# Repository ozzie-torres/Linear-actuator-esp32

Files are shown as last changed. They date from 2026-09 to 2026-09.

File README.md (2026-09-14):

# ESP32 Linear Actuator Controller

PlatformIO/Arduino firmware for independently testing two STEP/DIR/ENABLE
stepper axes from a responsive web interface. Motion is generated by
FastAccelStepper using the ESP32 MCPWM/PCNT peripherals, so Wi-Fi requests do
not determine pulse timing.

This repository has two deliberate roles:

1. `src/main.ino` is the working hardware bring-up and diagnostic firmware. It
   verifies wiring, directions, limits, speeds, and mechanics without pretending
   to be a CNC controller.
2. `fluidnc/config.yaml` is the validated migration configuration for FluidNC,
   which will provide proper homing, coordinated X/Y interpolation, machine and
   work coordinates, and G-code file execution.

## Current project state and handoff

As of 2026-09-14, the hardware has completed both diagnostic-firmware bring-up
and FluidNC commissioning. Official FluidNC v4.0.3, its WebUI filesystem, and
`fluidnc/config.yaml` are installed on the ESP32. Both axes move reliably, both
limit inputs have been electrically and mechanically verified, negative machine
motion travels toward the minimum/home switches, and FluidNC's complete `$H`
cycle succeeds in X-then-Y order. A final coordinate test moved X and Y from
machine zero to 5.000 mm and returned both to 0.000 mm with the controller Idle.
The WebUI then uploaded `gcode/first_motion_test.gcode` to LocalFS; FluidNC ran
it through `$LocalFS/Run`, reported `Program End`, and returned to Idle at X0/Y0.

The A4988 MS1/MS2/MS3 DIP switches are now all ON for 1/16 microstepping. Each
axis uses a 1.8-degree, 200-step/revolution NEMA-17, a GT2 belt, and a 20-tooth
pulley. Therefore:

```text
200 full steps/rev * 16 microsteps / (20 teeth * 2 mm) = 80 steps/mm
1 microstep = 0.0125 mm commanded resolution
```

Measured travel from the home position to the opposite mechanical end is 520 mm
on X and 460 mm on Y. FluidNC intentionally uses smaller 510 mm and 450 mm
software travels, leaving 10 mm before each positive mechanical end. Earlier
96.5 mm X and approximately 100 mm Y observations were calibration moves, not
the full machine envelope.

The official FluidNC v4.0.3 Windows bundle and current official validator are
available locally under ignored `.tools/`. `fluidnc/config.yaml` passes the
official validator and is the configuration currently running on the machine.
FluidNC station credentials are stored in ESP32 nonvolatile settings rather
than this repository. At commissioning time it joined the local network at
`http://10.0.0.68/` and advertised `http://fluidnc-stage.local/`; DHCP may assign
a different numeric address later.

## Hardware

| Signal | ESP32 pin | Notes |
| --- | ---: | --- |
| X STEP | GPIO 25 | MCPWM-generated pulse output |
| X DIR | GPIO 26 | Positive/negative X direction |
| X ENABLE | GPIO 27 | Active LOW; enabled after safe initialization |
| Y STEP | GPIO 16 | MCPWM-generated pulse output |
| Y DIR | GPIO 17 | Positive/negative Y direction |
| Y ENABLE | GPIO 22 | Active LOW; enabled after safe initialization |
| X minimum/home switch | GPIO 32 | NO contact to GND; internal pull-up |
| Y minimum/home switch | GPIO 13 | NO contact to GND; internal pull-up |

Connect ESP32 ground to the stepper driver's logic/power ground. Never connect
or disconnect motor coils while the driver is powered. Set the driver's current
limit for the connected motor before extended operation.

Each normally-open limit switch connects only its assigned GPIO to GND when
pressed. The internal pull-up makes an unpressed switch read HIGH and a pressed
switch read LOW, so no external resistor is required. The manual API blocks
negative motion while its minimum switch is pressed, but permits positive
motion so the operator can back away. NO wiring is minimal but not fail-safe: a
broken wire looks like an unpressed switch. GPIO 18/19/23/5 are deliberately
reserved for a future VSPI SD card.

Both FluidNC direction pins use plain polarity (`gpio.26` and `gpio.17`). During
commissioning, the earlier inverted X setting moved away from home; removing
`:low` made negative coordinate motion travel toward each switch. Revalidate
this behavior if any motor leads, driver connections, or transmission changes.

### Motion hardware

- Two A4988 StepStick drivers, configured by carrier-board DIP switches
- MS1, MS2, and MS3 all ON: 1/16 microstepping
- Two 1.8-degree NEMA-17 motors (200 full steps/revolution)
- GT2 2 mm-pitch belts with 20-tooth pulleys
- X calibration: 80 steps/mm; physical travel: 520 mm; soft travel: 510 mm
- Y calibration: 80 steps/mm; physical travel: 460 mm; soft travel: 450 mm

## Build and configuration

1. Install PlatformIO.
2. Copy `src/secrets.example.h` to `src/secrets.h`.
3. Set the 2.4 GHz station credentials and direct access-point credentials.
4. Run `pio run` to build.
5. Run `pio run --target upload --upload-port COM4` (adjust the port as needed).
6. Use a 115200-baud serial monitor to read assigned IP addresses.

`src/secrets.h` is intentionally ignored by Git. If it is absent, the example
placeholder values are used so a clean checkout can still compile.

The only external Arduino library is pinned in `platformio.ini`:

- FastAccelStepper 0.31.8

## Diagnostic-firmware network behavior

The ESP32 starts in AP+station mode:

- It selects the strongest matching 2.4 GHz access point and retains the
  strongest WPA2-only radio as a compatibility fallback.
- It also exposes the configured direct AP, normally reachable at
  `http://192.168.4.1`.
- Station failure does not prevent the direct AP or web server from operating.

Wi-Fi station power saving is disabled to reduce interactive latency. The web
page also permits only one status request at a time, preventing slow polls from
accumulating ahead of motion commands on the synchronous ESP32 WebServer.

The installed FluidNC firmware uses station-with-AP-fallback mode (`STA>AP`),
DHCP, and hostname `fluidnc-stage`. Network credentials live in FluidNC NVS and
are intentionally absent from Git. Use the FluidNC WebUI, USB serial, or a G-code
sender for normal machine control; the custom HTTP API below belongs only to the
diagnostic firmware and is not served while FluidNC is installed.

## HTTP API

| Method | Path | Purpose |
| --- | --- | --- |
| GET | `/` | Embedded mobile control page |
| GET | `/status` | Nested X/Y position, motion, settings, and limit state |
| POST | `/move` | Relative move; `axis=x|y`, `direction=positive|negative` |
| POST | `/stop` | Controlled stop; `axis=x|y|all` |
| POST | `/zero` | Zero selected `axis=x|y` while stopped |
| POST | `/settings` | Apply settings to selected `axis=x|y` |

## Motion and position semantics

FastAccelStepper queues motion and produces pulses independently of Arduino's
`loop()`. `loop()` only services the synchronous web server. Position remains
open-loop: PCNT counts generated STEP pulses, but there is no encoder confirming
that the motor physically moved. STOP decelerates normally rather than removing
torque abruptly.

The future `homeStepper()` placeholder describes the intended switch sequence.
Implement it as a non-blocking state machine so web requests and STOP remain
responsive.

### Known diagnostic-firmware limitations

- `homeStepper()` is intentionally a documented placeholder; there is no
  automatic `/home` endpoint. The successful calibration homing was supervised
  using bounded API moves: seek, interrupt stop, 3 mm pull-off, slow approach,
  and `setCurrentPosition(0)`.
- Limit switches are normally open to minimize component count. A broken wire
  therefore looks like a safe, released switch. Normally-closed switches and a
  physical emergency stop are recommended before unattended machine use.
- The diagnostic ISR force-stops an axis on every falling limit edge, regardless
  of movement direction. Mechanical contact bounce can interrupt a move away
  from the switch; this was observed during pull-off and handled with a second
  bounded move. FluidNC replaces this temporary behavior with its homing logic.
- X and Y are independently commanded. This firmware does not calculate a
  coordinated line, arc, junction velocity, or tool path.
- Position is commanded open-loop position and resets when firmware restarts.
  There are no motor encoders.
- The drivers remain enabled after safe initialization to preserve holding
  position. A4988 current limits must be adjusted correctly, and driver/motor
  temperature must be monitored.
- There is currently no dedicated hardware emergency-stop input.

## CNC/G-code controller

The custom firmware remains an electrical and mechanical diagnostic tool; it
does not coordinate axes or interpret G-code. The machine has now migrated to
FluidNC, which provides coordinated interpolation, machine/work coordinates,
homing, hard/soft limits, WebUI control, and execution of uploaded or SD-card
G-code without maintaining a custom motion planner.

The validated migration configuration is in `fluidnc/config.yaml`. It records
the A4988 1/16 microstep setting, 20-tooth GT2 calibration (80 steps/mm),
commissioned direction polarity, conservative travel limits, and sequential X/Y
homing. Keep the diagnostic firmware in Git for future electrical troubleshooting;
reflashing it would replace FluidNC on the ESP32.

## FluidNC commissioning

Official FluidNC v4.0.3 was installed and tested. Review release notes and
revalidate the YAML before upgrading to another version. The running
configuration uses:

- ESP32 RMT hardware stepping
- Cartesian X/Y kinematics
- 80 steps/mm on both axes
- 750 mm/min initial maximum rate
- 10 mm/s^2 initial acceleration
- X then Y sequential two-pass homing
- 300 mm/min seek, 60 mm/min precision approach, and 3 mm pull-off
- 125% homing search distance on each axis. This does not expand the 510/450 mm
  soft-limited working envelopes; it only ensures homing can find a switch from
  anywhere inside the measured physical travel.
- Active-low inputs with internal pull-ups (`gpio.32:low:pu` and
  `gpio.13:low:pu`)
- A4988 active-high disable semantics on GPIO 27 and GPIO 22
- Hard limits, soft limits, and mandatory homing after restart

The 2026-09-14 commissioning record is:

1. Erased the ESP32 and installed the official Wi-Fi image plus WebUI filesystem.
2. Uploaded the validated YAML as `/littlefs/config.yaml`; the complete startup
   report parsed every assigned pin without an error.
3. With motor power off, pressed X and Y individually and observed `Pn:X` and
   `Pn:Y`; both cleared when released. `$MD` drove both active-low A4988 ENABLE
   inputs to the safe 3.3 V disabled level.
4. Initial X homing exposed reversed FluidNC direction polarity. X and Y were
   corrected to plain `gpio.26` and `gpio.17` direction pins.
5. X's initial 110% homing search expired a few millimeters before the switch.
   Both axes now use 125%, providing margin for a start at the far end.
6. `$HX` and `$HY` each completed their seek, pull-off, slow approach, and zero.
   A subsequent full `$H` reported `Homed:X`, then `Homed:Y`.
7. Final status was `Idle|MPos:0.000,0.000,0.000` with no active limit pins.
8. `G91 G1 X5 F300`, followed by `G1 Y5 F300`, produced machine position
   X5.000/Y5.000. `G90 G0 X0 Y0` returned both axes to machine zero.
9. Uploaded `gcode/first_motion_test.gcode` through the WebUI Local Filesystem
   panel. `$LocalFS/Show` verified its contents, and
   `$LocalFS/Run=first_motion_test.gcode` traced the 10 mm square, reported
   `Program End`, and finished Idle at machine X0/Y0 without an alarm.

Before the first real process, measure commanded travel accurately, refine
steps/mm if necessary, dry-run a small G-code file unloaded, and add a physical
normally-closed emergency stop. Open-loop step counts do not prove that the
mechanism moved without losing steps.

The standard VSPI pins GPIO 18/19/23/5 remain unused, allowing a later SD-card
interface. FluidNC can initially upload and run small G-code files from its
local flash filesystem, so an SD-card module is not required for first tests.

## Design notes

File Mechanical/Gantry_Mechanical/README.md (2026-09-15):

# Gantry mechanical source archives

These archives were copied without modification on 2026-09-14 from the local
project staging folder:

```text
C:\Users\oswak\Downloads\Gantry_Mechanical
```

They are retained as source/reference material for the mechanical gantry. Keep
the archives intact so their included documentation and license files remain
associated with the models.

## Inventory

| Archive | Size (bytes) | Contents |
| --- | ---: | --- |
| `Bearing.zip` | 8,946 | Four STEP bearing-ring models |
| `Ender 3 Cable Chain, no screws, no unplug cable - 3769941.zip` | 37,333,163 | STL models, example printer G-code, images, README, and license |
| `OpenBuilds V-Slot™ Linear Actuators - 69004.zip` | 10,980,258 | STL models, SketchUp archive, videos, images, README, and license |

## SHA-256

```text
CAE7529FF7CB6AD6EE9F38342CB6ACBF9A29103679AFB2D44184CCF375C05788  Bearing.zip
5A4FB7F57B66F34E2335126229D11A3E3F31087A7461ACAC9656E7646BA6F5CC  Ender 3 Cable Chain, no screws, no unplug cable - 3769941.zip
3998BE7D92216873D7F42F55A696A5199EF6B55E0BB58AB76DEFDA88F2F09FDB  OpenBuilds V-Slot™ Linear Actuators - 69004.zip
```

The hashes above matched the source downloads when copied.

## Safety and reuse notes

- The cable-chain archive contains `G1.gcode`, `G2.gcode`, and `G3.gcode` for a
  different machine. Do not send them to this FluidNC gantry without reviewing
  coordinates, units, feeds, tool commands, and machine limits.
- Review each archive's bundled `LICENSE.txt` before redistributing or modifying
  its content. `Bearing.zip` does not contain an embedded license file, so its
  reuse terms must be established separately.
- The three top-level V-Slot STL files already present in `Mechanical/` also
  occur inside the OpenBuilds archive; they are intentionally not overwritten.

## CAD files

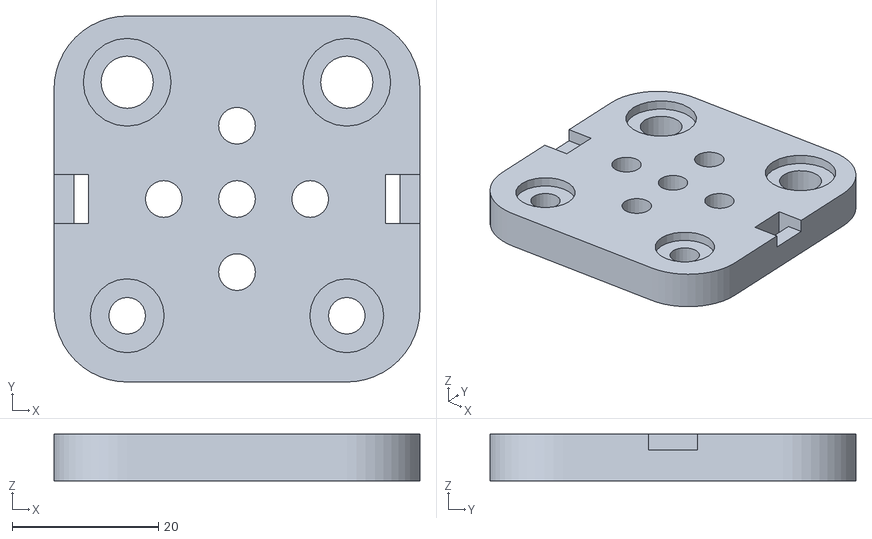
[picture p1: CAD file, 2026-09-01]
Mechanical/VSLOT_Mini_V_Plate.stl
50.0 x 50.0 x 6.36

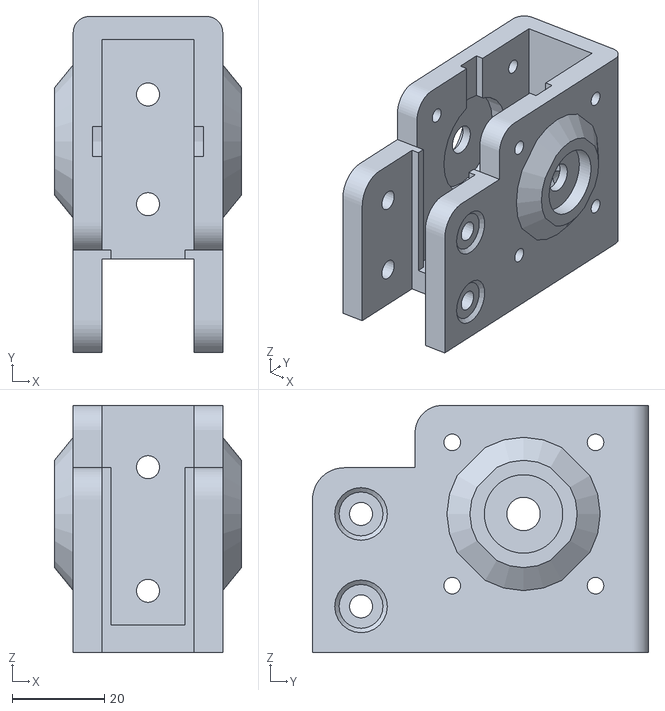
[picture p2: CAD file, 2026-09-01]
Mechanical/VSLOT_Mini_V_Linear_Guide_40mm.stl
40.5 x 72.7 x 53.5

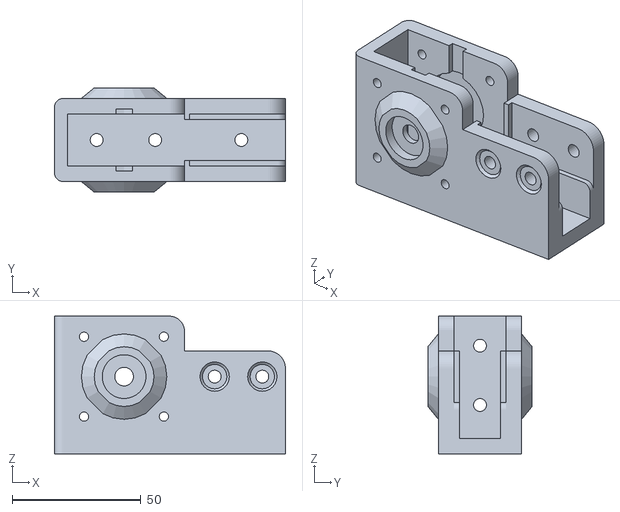
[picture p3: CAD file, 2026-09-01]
Mechanical/VSLOT_Mini_V_Linear_Guide_20mm.stl
89.7 x 40.5 x 53.5

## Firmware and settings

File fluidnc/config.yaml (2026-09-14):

# FluidNC configuration for the two-axis GT2 belt stage.
#
# Hardware calibration:
# - 1.8 degree NEMA-17 motors: 200 full steps/revolution
# - A4988 drivers with MS1/MS2/MS3 all ON: 1/16 microstepping
# - GT2 belt with 20-tooth pulley: 40 mm/revolution
# - 200 * 16 / 40 = 80 steps/mm
#
# Measured travel from home to the opposite mechanical end is 520 mm (X) and
# 460 mm (Y). Conservative 510 mm and 450 mm software travels leave 10 mm of
# margin before the far-end mechanical stops.
# Revalidate steps/mm, direction, and travel after any mechanical change.

board: ESP32-WROOM-32 Dev Module
name: Two Axis GT2 Belt Stage
meta: GPIO STEP/DIR A4988 controller; calibrated 2026-09-14

kinematics:
  Cartesian:

stepping:
  engine: RMT
  # FluidNC treats 255 as "never automatically disable." Holding torque keeps
  # the open-loop machine coordinates valid while the controller is powered.
  idle_ms: 255
  pulse_us: 4
  dir_delay_us: 1
  disable_delay_us: 0

axes:
  # Each axis makes a coarse touch and a slow precision touch during homing.
  homing_runs: 2

  x:
    steps_per_mm: 80.000
    max_rate_mm_per_min: 750.000
    acceleration_mm_per_sec2: 10.000
    max_travel_mm: 510.000
    soft_limits: true
    homing:
      # Home X first, toward its negative-end switch.
      cycle: 1
      allow_single_axis: true
      positive_direction: false
      mpos_mm: 0.000
      feed_mm_per_min: 60.000
      seek_mm_per_min: 300.000
      settle_ms: 500
      # Commissioning from the far end showed that 110% stopped a few
      # millimeters before the physical switch. 125% provides search margin;
      # it does not expand the 510 mm soft-limited working envelope.
      seek_scaler: 1.250
      feed_scaler: 1.100
    motor0:
      # NO switch to GND. :low makes LOW active; :pu enables the pull-up.
      limit_neg_pin: gpio.32:low:pu
      limit_pos_pin: NO_PIN
      limit_all_pin: NO_PIN
      hard_limits: true
      pulloff_mm: 3.000
      stepstick:
        step_pin: gpio.25
        # FluidNC commissioning showed that the inverted polarity moved X away
        # from its negative home switch. The plain pin makes negative machine
        # motion travel toward the X home switch on this assembled mechanism.
        direction_pin: gpio.26
        # A4988 ENABLE is LOW to run and HIGH to disable. FluidNC's disable
        # signal is active HIGH by default, so this pin must not use :low.
        disable_pin: gpio.27
        # The carrier-board DIP switches set all three pins HIGH for 1/16.
        ms1_pin: NO_PIN
        ms2_pin: NO_PIN
        ms3_pin: NO_PIN
        reset_pin: NO_PIN
    motor1:
      null_motor:

  y:
    steps_per_mm: 80.000
    max_rate_mm_per_min: 750.000
    acceleration_mm_per_sec2: 10.000
    max_travel_mm: 450.000
    soft_limits: true
    homing:
      # Home Y after X, toward its negative-end switch.
      cycle: 2
      allow_single_axis: true
      positive_direction: false
      mpos_mm: 0.000
      feed_mm_per_min: 60.000
      seek_mm_per_min: 300.000
      settle_ms: 500
      # Match the extra search margin proven during X commissioning. This only
      # extends the homing search and does not change the 450 mm soft limit.
      seek_scaler: 1.250
      feed_scaler: 1.100
    motor0:
      limit_neg_pin: gpio.13:low:pu
      limit_pos_pin: NO_PIN
      limit_all_pin: NO_PIN
      hard_limits: true
      pulloff_mm: 3.000
      stepstick:
        step_pin: gpio.16
        # The two axes use matching A4988 direction wiring. Plain polarity made
        # negative X motion travel toward home, so Y uses the same convention.
        direction_pin: gpio.17
        disable_pin: gpio.22
        ms1_pin: NO_PIN
        ms2_pin: NO_PIN
        ms3_pin: NO_PIN
        reset_pin: NO_PIN
    motor1:
      null_motor:

start:
  # Require a successful $H after each controller restart before normal moves.
  must_home: true
  check_limits: true

control:
  # Add a dedicated normally-closed emergency-stop input before unattended use.
  estop_pin: NO_PIN
  safety_door_pin: NO_PIN

probe:
  pin: NO_PIN

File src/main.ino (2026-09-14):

#include <Arduino.h>
#include <WiFi.h>
#include <WebServer.h>
#include <FastAccelStepper.h>

/**
 * ESP32 web-controlled STEP/DIR linear actuator controller.
 *
 * Architecture:
 * - FastAccelStepper queues acceleration profiles and generates STEP pulses with
 *   ESP32 MCPWM hardware. PCNT tracks the commanded pulse position.
 * - WebServer handles a small REST-style API and an embedded mobile webpage.
 * - Wi-Fi runs in AP+station mode. The direct AP remains usable when the
 *   configured infrastructure network is unavailable.
 * - Motion is open-loop: position is the commanded pulse count, not encoder
 *   feedback. A stalled motor will therefore make reported and physical
 *   positions disagree.
 *
 * Safety invariants:
 * - ENABLE is active LOW and remains HIGH until setup completes.
 * - No movement is issued during boot.
 * - Zeroing is rejected while the hardware queue is moving.
 * - STOP requests normal acceleration-limited deceleration.
 */

// Keep real credentials out of source control. A clean clone still compiles
// with obvious placeholders, but a deployed device should use src/secrets.h.
#if __has_include("secrets.h")
#include "secrets.h"
#else
#include "secrets.example.h"
#warning "Using placeholder network credentials from secrets.example.h"
#endif

// -------------------- Hardware pins --------------------
// X retains the original wiring. Y uses ordinary output-capable GPIOs that are
// neither boot-strapping pins nor input-only pins on this ESP32-WROOM-32 board.
// GPIO 18/19/23/5 remain free for a future VSPI SD-card interface. GPIO 21
// remains available if a future I2C bus is needed; its clock can be reassigned
// because GPIO 22 is used by Y ENABLE.
#define X_STEP_PIN 25
#define X_DIR_PIN 26
#define X_ENABLE_PIN 27
#define Y_STEP_PIN 16
#define Y_DIR_PIN 17
#define Y_ENABLE_PIN 22

// One minimum/home switch is assigned to each axis. Wire each switch's normally
// open (NO) contact between its GPIO and GND. Both pins have internal pull-ups,
// so no external resistors or 3.3 V switch wiring are required. An unpressed
// switch reads HIGH and a pressed switch reads LOW. Unlike NC wiring, a broken
// wire cannot be detected and will look like an unpressed switch.
#define X_LIMIT_PIN 32
#define Y_LIMIT_PIN 13
constexpr uint8_t LIMIT_TRIGGERED_LEVEL = LOW;

// Bench calibration confirmed that LOW on each DIR pin must count upward so
// negative coordinate motion travels toward the minimum/home switch. Change
// these values only if the driver/motor wiring changes; never rewire energized
// motor coils to correct coordinate direction.
constexpr bool X_DIRECTION_HIGH_COUNTS_UP = false;
constexpr bool Y_DIRECTION_HIGH_COUNTS_UP = false;

// -------------------- Motor and web server state --------------------
// The engine owns the ESP32 pulse peripherals. The pointer is null only if the
// requested STEP pin/peripheral could not be allocated during setup.
FastAccelStepperEngine stepperEngine;
WebServer server(80);

constexpr long DEFAULT_MOVE_STEPS = 200;
constexpr float DEFAULT_MAX_SPEED = 1000.0F;
constexpr float DEFAULT_ACCELERATION = 500.0F;

/** Runtime state and hardware assignment for one independently movable axis. */
struct AxisState {
  const char *name;
  uint8_t stepPin;
  uint8_t directionPin;
  uint8_t enablePin;
  uint8_t limitPin;
  bool directionHighCountsUp;
  FastAccelStepper *stepper;
  long requestedSteps;
  float configuredMaxSpeed;
  float configuredAcceleration;
  volatile bool limitEventPending;
};

// Settings are changed only by HTTP handlers on the Arduino application task.
// Only limitEventPending is shared with an ISR and is therefore volatile.
AxisState axisX = {"X", X_STEP_PIN, X_DIR_PIN, X_ENABLE_PIN, X_LIMIT_PIN,
                   X_DIRECTION_HIGH_COUNTS_UP,
                   nullptr, DEFAULT_MOVE_STEPS, DEFAULT_MAX_SPEED,
                   DEFAULT_ACCELERATION, false};
AxisState axisY = {"Y", Y_STEP_PIN, Y_DIR_PIN, Y_ENABLE_PIN, Y_LIMIT_PIN,
                   Y_DIRECTION_HIGH_COUNTS_UP,
                   nullptr, DEFAULT_MOVE_STEPS, DEFAULT_MAX_SPEED,
                   DEFAULT_ACCELERATION, false};

// The entire UI lives in flash, avoiding a filesystem dependency. Keep named
// JavaScript functions expressed as arrow functions: Arduino's .ino preprocessor
// can otherwise mistake JavaScript `function` declarations for C++ and inject
// invalid prototypes into this raw string.
const char INDEX_HTML[] PROGMEM = R"HTML(
<!doctype html>
<html lang="en">
<head>
  <meta charset="utf-8">
  <meta name="viewport" content="width=device-width,initial-scale=1,maximum-scale=1">
  <title>ESP32 Stepper</title>
  <style>
    :root { color-scheme: dark; font-family: -apple-system, BlinkMacSystemFont, "Segoe UI", sans-serif; }
    body { margin: 0; background: #111827; color: #f9fafb; }
    main { max-width: 560px; margin: auto; padding: 18px; }
    h1 { font-size: 1.55rem; margin: 6px 0 18px; }
    .card { background: #1f2937; border-radius: 16px; padding: 16px; margin-bottom: 14px; box-shadow: 0 5px 20px #0005; }
    .axes { display: grid; gap: 14px; }
    .axis-title { display: flex; align-items: center; justify-content: space-between; margin-bottom: 10px; }
    .axis-title h2 { margin: 0; font-size: 1.3rem; }
    .position { text-align: center; font-size: 2.5rem; font-variant-numeric: tabular-nums; overflow-wrap: anywhere; }
    .label { color: #9ca3af; font-size: .85rem; text-align: center; }
    .buttons { display: grid; grid-template-columns: 1fr 1fr; gap: 12px; }
    button { min-height: 64px; border: 0; border-radius: 13px; color: white; font-size: 1.15rem; font-weight: 700; touch-action: manipulation; }
    button:active { transform: scale(.98); }
    .move { background: #2563eb; }
    .stop { background: #dc2626; grid-column: 1 / -1; }
    .zero { background: #4b5563; width: 100%; margin-top: 12px; }
    .all-stop { width: 100%; margin-bottom: 14px; background: #991b1b; }
    .limit { border-radius: 999px; padding: 5px 9px; background: #065f46; font-size: .75rem; font-weight: 700; }
    .limit.hit { background: #b91c1c; }
    .fields { display: grid; gap: 12px; }
    label { color: #d1d5db; font-size: .9rem; }
    input { box-sizing: border-box; width: 100%; min-height: 50px; margin-top: 5px; padding: 10px 12px; border: 1px solid #4b5563; border-radius: 10px; background: #111827; color: white; font-size: 1.05rem; }
    .save { width: 100%; margin-top: 14px; background: #059669; }
    [id$="State"], #message { text-align: center; margin-top: 10px; color: #9ca3af; min-height: 1.2em; }
    #message.error { color: #fca5a5; }
  </style>
</head>
<body><main>
  <h1>ESP32 Two-Axis Control</h1>
  <button class="all-stop" id="stopAll">STOP BOTH AXES</button>
  <div class="axes">
  <section class="card" data-axis="x">
    <div class="axis-title"><h2>X Axis</h2><span id="xLimit" class="limit">LIMIT --</span></div>
    <div class="label">CURRENT POSITION (STEPS)</div>
    <div id="xPosition" class="position">--</div>
    <div id="xState">Connecting...</div>
    <div class="buttons">
      <button class="move" id="xNegative">X-</button>
      <button class="move" id="xPositive">X+</button>
      <button class="stop" id="xStop">STOP X</button>
    </div>
    <button class="zero" id="xZero">Zero X Position</button>
    <div class="fields">
      <label>Move distance (steps)<input id="xSteps" type="number" min="1" step="1" value="200"></label>
      <label>Max speed (steps/sec)<input id="xSpeed" type="number" min="1" step="1" value="1000"></label>
      <label>Acceleration (steps/sec&sup2;)<input id="xAccel" type="number" min="1" step="1" value="500"></label>
      <button class="save" id="xSave">Apply X Settings</button>
    </div>
  </section>
  <section class="card" data-axis="y">
    <div class="axis-title"><h2>Y Axis</h2><span id="yLimit" class="limit">LIMIT --</span></div>
    <div class="label">CURRENT POSITION (STEPS)</div>
    <div id="yPosition" class="position">--</div>
    <div id="yState">Connecting...</div>
    <div class="buttons">
      <button class="move" id="yNegative">Y-</button>
      <button class="move" id="yPositive">Y+</button>
      <button class="stop" id="yStop">STOP Y</button>
    </div>
    <button class="zero" id="yZero">Zero Y Position</button>
    <div class="fields">
      <label>Move distance (steps)<input id="ySteps" type="number" min="1" step="1" value="200"></label>
      <label>Max speed (steps/sec)<input id="ySpeed" type="number" min="1" step="1" value="1000"></label>
      <label>Acceleration (steps/sec&sup2;)<input id="yAccel" type="number" min="1" step="1" value="500"></label>
      <button class="save" id="ySave">Apply Y Settings</button>
    </div>
  </section>
  </div>
  <div id="message"></div>
</main>
<script>
const $ = id => document.getElementById(id);
const initialized = {x: false, y: false};
let commandInFlight = false;
let statusRequestInFlight = false;

// POST form data to one API endpoint and surface firmware errors in the page.
const post = async (path, values = {}) => {
  // Status polling is paused while a command is in flight. This keeps the
  // synchronous ESP32 WebServer queue clear for motion and STOP requests.
  commandInFlight = true;
  const body = new URLSearchParams(values);
  try {
    const response = await fetch(path, {method: 'POST', headers: {'Content-Type': 'application/x-www-form-urlencoded'}, body});
    const result = await response.json();
    if (!response.ok) throw new Error(result.error || ('HTTP ' + response.status));
    $('message').textContent = result.message || '';
    $('message').className = '';
    updateStatus();
  } catch (error) {
    $('message').textContent = error.message;
    $('message').className = 'error';
  } finally {
    commandInFlight = false;
  }
};

const settings = axis => {
  return {axis, steps: $(axis + 'Steps').value, maxSpeed: $(axis + 'Speed').value, acceleration: $(axis + 'Accel').value};
};

// These discrete click handlers can later become pointerdown/pointerup handlers
// backed by /jog/start and /jog/stop without changing the existing move API.
for (const axis of ['x', 'y']) {
  $(axis + 'Negative').addEventListener('click', () => post('/move', {...settings(axis), direction: 'negative'}));
  $(axis + 'Positive').addEventListener('click', () => post('/move', {...settings(axis), direction: 'positive'}));
  $(axis + 'Stop').addEventListener('click', () => post('/stop', {axis}));
  $(axis + 'Zero').addEventListener('click', () => post('/zero', {axis}));
  $(axis + 'Save').addEventListener('click', () => post('/settings', settings(axis)));
}
$('stopAll').addEventListener('click', () => post('/stop', {axis: 'all'}));

// Polling is intentionally independent of motion generation. MCPWM continues
// producing stable pulses even when a network request is delayed.
const updateStatus = async () => {
  // setInterval can fire again before a slow fetch completes. Without this
  // guard those requests accumulate and make button commands appear laggy.
  if (commandInFlight || statusRequestInFlight) return;
  statusRequestInFlight = true;
  try {
    const response = await fetch('/status', {cache: 'no-store'});
    if (!response.ok) throw new Error('Status unavailable');
    const data = await response.json();
    for (const axis of ['x', 'y']) {
      const state = data[axis];
      $(axis + 'Position').textContent = state.currentPosition;
      $(axis + 'State').textContent = state.moving ? `Moving to ${state.targetPosition} (${state.distanceToGo} remaining)` : 'Stopped';
      const limit = $(axis + 'Limit');
      limit.textContent = state.limitTriggered ? 'LIMIT PRESSED' : 'LIMIT OK';
      limit.className = state.limitTriggered ? 'limit hit' : 'limit';
      if (!initialized[axis]) {
        $(axis + 'Speed').value = state.maxSpeed;
        $(axis + 'Accel').value = state.acceleration;
        $(axis + 'Steps').value = state.requestedSteps;
        initialized[axis] = true;
      }
    }
  } catch (error) {
    $('xState').textContent = error.message;
    $('yState').textContent = error.message;
  } finally {
    statusRequestInFlight = false;
  }
};
updateStatus();
setInterval(updateStatus, 500);
</script></body></html>
)HTML";

// -------------------- HTTP helpers and API handlers --------------------
/** Send a JSON response with caching disabled so position is never stale. */
void sendJson(int statusCode, const String &json) {
  server.sendHeader("Cache-Control", "no-store");
  server.send(statusCode, "application/json", json);
}

/** Parse a required positive base-10 integer form argument. */
bool parsePositiveLong(const String &name, long &value) {
  if (!server.hasArg(name) || server.arg(name).isEmpty()) return false;
  char *end = nullptr;
  const String text = server.arg(name);
  const long parsed = strtol(text.c_str(), &end, 10);
  if (*end != '\0' || parsed <= 0) return false;
  value = parsed;
  return true;
}

/** Parse a required positive finite floating-point form argument. */
bool parsePositiveFloat(const String &name, float &value) {
  if (!server.hasArg(name) || server.arg(name).isEmpty()) return false;
  char *end = nullptr;
  const String text = server.arg(name);
  const float parsed = strtof(text.c_str(), &end);
  if (*end != '\0' || !isfinite(parsed) || parsed <= 0.0F) return false;
  value = parsed;
  return true;
}

/** Resolve the required `axis=x|y` form argument to its runtime object. */
AxisState *axisFromRequest() {
  if (!server.hasArg("axis")) {
    Serial.println("ERROR: axis argument missing");
    sendJson(400, "{\"error\":\"Axis must be x or y\"}");
    return nullptr;
  }
  const String requestedAxis = server.arg("axis");
  if (requestedAxis == "x") return &axisX;
  if (requestedAxis == "y") return &axisY;
  Serial.printf("ERROR: unsupported axis '%s'\n", requestedAxis.c_str());
  sendJson(400, "{\"error\":\"Axis must be x or y\"}");
  return nullptr;
}

/** Validate and apply request settings to one hardware ramp generator. */
bool applySettingsFromRequest(AxisState &axis, bool requireSteps) {
  long newSteps = axis.requestedSteps;
  float newSpeed = axis.configuredMaxSpeed;
  float newAcceleration = axis.configuredAcceleration;

  if ((requireSteps || server.hasArg("steps")) && !parsePositiveLong("steps", newSteps)) {
    Serial.printf("ERROR: invalid %s move distance\n", axis.name);
    sendJson(400, "{\"error\":\"Move distance must be a positive integer\"}");
    return false;
  }
  if (server.hasArg("maxSpeed") && !parsePositiveFloat("maxSpeed", newSpeed)) {
    sendJson(400, "{\"error\":\"Max speed must be positive\"}");
    return false;
  }
  if (server.hasArg("acceleration") && !parsePositiveFloat("acceleration", newAcceleration)) {
    sendJson(400, "{\"error\":\"Acceleration must be positive\"}");
    return false;
  }
  if (newSpeed < 1.0F || newSpeed > static_cast<float>(INT32_MAX) ||
      newAcceleration < 1.0F || newAcceleration > static_cast<float>(INT32_MAX)) {
    sendJson(400, "{\"error\":\"Speed or acceleration is outside the supported range\"}");
    return false;
  }

  const uint32_t speedHz = static_cast<uint32_t>(lroundf(newSpeed));
  const int32_t acceleration = static_cast<int32_t>(lroundf(newAcceleration));
  if (axis.stepper != nullptr &&
      (axis.stepper->setSpeedInHz(speedHz) != 0 ||
       axis.stepper->setAcceleration(acceleration) != 0)) {
    sendJson(400, "{\"error\":\"Speed or acceleration is outside motor-controller limits\"}");
    return false;
  }

  const bool changed = newSpeed != axis.configuredMaxSpeed ||
                       newAcceleration != axis.configuredAcceleration;
  axis.requestedSteps = newSteps;
  axis.configuredMaxSpeed = static_cast<float>(speedHz);
  axis.configuredAcceleration = static_cast<float>(acceleration);
  if (changed && axis.stepper != nullptr && axis.stepper->isRunning() &&
      !axis.stepper->isStopping()) {
    axis.stepper->applySpeedAcceleration();
  }
  return true;
}

/** Serialize one axis using hardware position and its fail-safe limit input. */
String axisStatusJson(const AxisState &axis) {
  const int32_t current = axis.stepper->getCurrentPosition();
  const int32_t target = axis.stepper->targetPos();
  const bool limitTriggered = digitalRead(axis.limitPin) == LIMIT_TRIGGERED_LEVEL;
  String json;
  json.reserve(230);
  json += "{\"currentPosition\":" + String(current);
  json += ",\"targetPosition\":" + String(target);
  json += ",\"distanceToGo\":" + String(target - current);
  json += ",\"moving\":" + String(axis.stepper->isRunning() ? "true" : "false");
  json += ",\"limitTriggered\":" + String(limitTriggered ? "true" : "false");
  json += ",\"maxSpeed\":" + String(axis.configuredMaxSpeed, 2);
  json += ",\"acceleration\":" + String(axis.configuredAcceleration, 2);
  json += ",\"requestedSteps\":" + String(axis.requestedSteps) + "}";
  return json;
}

/** GET /status: return both axes' motion and limit state as JSON. */
void handleStatus() {
  if (axisX.stepper == nullptr || axisY.stepper == nullptr) {
    sendJson(503, "{\"error\":\"One or more motor pulse engines are unavailable\"}");
    return;
  }
  String json = "{\"x\":" + axisStatusJson(axisX);
  json += ",\"y\":" + axisStatusJson(axisY) + "}";
  sendJson(200, json);
}

/** POST /move: queue a positive or negative relative move on one axis. */
void handleMove() {
  AxisState *axis = axisFromRequest();
  if (axis == nullptr) return;
  if (axis->stepper == nullptr) {
    sendJson(503, "{\"error\":\"Motor pulse engine is unavailable\"}");
    return;
  }
  if (!applySettingsFromRequest(*axis, true)) return;
  if (!server.hasArg("direction")) {
    sendJson(400, "{\"error\":\"Direction must be positive or negative\"}");
    return;
  }

  const String direction = server.arg("direction");
  long signedSteps;
  if (direction == "positive" || direction == "right") signedSteps = axis->requestedSteps;
  else if (direction == "negative" || direction == "left") signedSteps = -axis->requestedSteps;
  else {
    sendJson(400, "{\"error\":\"Direction must be positive or negative\"}");
    return;
  }

  // Each switch protects the negative/minimum end. Positive motion remains
  // available to back off and close an opened limit-switch circuit.
  if (signedSteps < 0 && digitalRead(axis->limitPin) == LIMIT_TRIGGERED_LEVEL) {
    Serial.printf("ERROR: %s negative move blocked by active limit\n", axis->name);
    sendJson(409, "{\"error\":\"Negative move blocked by active limit switch\"}");
    return;
  }

  const int8_t result = axis->stepper->move(static_cast<int32_t>(signedSteps));
  if (result != MOVE_OK) {
    Serial.printf("ERROR: %s move rejected with code %d\n", axis->name, result);
    sendJson(409, "{\"error\":\"Motor controller rejected the move\"}");
    return;
  }
  Serial.printf("%s move: %s, steps: %ld, target: %ld\n", axis->name,
                direction.c_str(), axis->requestedSteps,
                static_cast<long>(axis->stepper->targetPos()));
  sendJson(200, "{\"message\":\"Move accepted\"}");
}

/** POST /stop: controlled-stop one selected axis or both axes. */
void handleStop() {
  const String requestedAxis = server.hasArg("axis") ? server.arg("axis") : "all";
  if (requestedAxis == "all") {
    if (axisX.stepper != nullptr) axisX.stepper->stopMove();
    if (axisY.stepper != nullptr) axisY.stepper->stopMove();
    Serial.println("STOP ALL command received");
  } else {
    AxisState *axis = axisFromRequest();
    if (axis == nullptr) return;
    if (axis->stepper == nullptr) {
      sendJson(503, "{\"error\":\"Motor pulse engine is unavailable\"}");
      return;
    }
    axis->stepper->stopMove();
    Serial.printf("STOP %s command received\n", axis->name);
  }
  sendJson(200, "{\"message\":\"Stopping\"}");
}

/** POST /zero: redefine one axis position as zero only at standstill. */
void handleZero() {
  AxisState *axis = axisFromRequest();
  if (axis == nullptr) return;
  if (axis->stepper == nullptr) {
    sendJson(503, "{\"error\":\"Motor pulse engine is unavailable\"}");
    return;
  }
  if (axis->stepper->isRunning()) {
    sendJson(409, "{\"error\":\"Stop the motor before zeroing\"}");
    return;
  }
  axis->stepper->setCurrentPosition(0);
  Serial.printf("Zero %s position command\n", axis->name);
  sendJson(200, "{\"message\":\"Position zeroed\"}");
}

/** POST /settings: validate and store settings for one selected axis. */
void handleSettings() {
  AxisState *axis = axisFromRequest();
  if (axis == nullptr) return;
  if (!applySettingsFromRequest(*axis, true)) return;
  Serial.printf("%s settings applied; distance: %ld steps\n",
                axis->name, axis->requestedSteps);
  sendJson(200, "{\"message\":\"Settings applied\"}");
}

/** Return a consistent JSON error for routes not registered in setup(). */
void handleNotFound() {
  Serial.printf("ERROR: HTTP 404 for %s\n", server.uri().c_str());
  sendJson(404, "{\"error\":\"Not found\"}");
}

/**
 * Hard-limit ISRs stop only the affected manual-test axis. forceStop() is
 * documented by FastAccelStepper as interrupt-safe and prevents a web request
 * from delaying limit response. Future coordinated CNC motion should stop all
 * axes and invalidate machine position; FluidNC supplies that behavior.
 */
void IRAM_ATTR handleXLimitInterrupt() {
  axisX.limitEventPending = true;
  if (axisX.stepper != nullptr) axisX.stepper->forceStop();
}
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
void loop() {
  // ISRs perform the time-critical stop; logging is deferred here because
  // Serial is not safe inside an interrupt handler.
  if (axisX.limitEventPending) {
    axisX.limitEventPending = false;
    Serial.println("X LIMIT PRESSED: X motion force-stopped");
  }
  if (axisY.limitEventPending) {
    axisY.limitEventPending = false;
    Serial.println("Y LIMIT PRESSED: Y motion force-stopped");
  }

  // FastAccelStepper generates queued pulses independently using ESP32 hardware.
  // The application loop only needs to keep the web server responsive.
  server.handleClient();
}

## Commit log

2026-09-01 Build documented ESP32 hardware-timed web stepper controller
    Create a complete PlatformIO Arduino firmware for an ESP32-controlled STEP/DIR/ENABLE linear actuator with a responsive embedded web interface and JSON HTTP API.
    Replace loop-polled AccelStepper timing with FastAccelStepper 0.31.8 and explicitly select the ESP32 MCPWM/PCNT backend. Motion profiles and STEP pulses now run from the hardware-backed queue independently of synchronous WebServer and Wi-Fi latency, while controlled stop, relative moves, current position, target position, zeroing, speed, and acceleration behavior remain available.
    Implement safe active-LOW enable sequencing, no automatic boot movement, rejected zero requ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
    [main.ino]
2026-09-01 Create Brackets
2026-09-14 Add calibrated two-axis diagnostics and FluidNC migration plan
    Expand the ESP32 bring-up firmware from one motor to independently controlled X and Y axes using FastAccelStepper's MCPWM/PCNT backend. Assign X STEP/DIR/ENABLE to GPIO 25/26/27, Y to GPIO 16/17/22, 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
    Record the bench-tested direction polarity so negative travel moves toward each home switch. Preserve safe startup with both active-low enables disabled until initialization completes, no automa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
    [config.yaml]
2026-09-14 Commission FluidNC homing and coordinated motion
    Install and document the proven FluidNC v4.0.3 machine state after live two-axis commissioning. Correct both A4988 direction pins to plain GPIO polarity so negative machine motion approaches the home switches, and increase both homing seek scalers to 1.25 after the original X search stopped just short of its switch.
    Record the complete safety and validation trail: individual NO limit-switch detection and release, active-low ENABLE outputs verified high while disabled, successful X-only and Y-only two-stage homing, successful sequential full homing, and a 5 mm X/Y coordinate move followed by a return to machine zero. Update the handoff documen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
    [config.yaml]
2026-09-14 Correct full gantry envelope and prove LocalFS G-code execution
    Replace the incorrectly inferred 95 x 98 mm work area with the measured home-to-far-end travel of 520 x 460 mm. Configure conservative 510 x 450 mm soft-limited travel so each positive mechanical end retains 10 mm of margin, while preserving the commissioned 80 steps/mm calibration, homing polarity, and 1.25 seek scaling.
    Add a safe machine-coordinate G-code program that uses no spindle output, remains within X/Y 5..15 mm, traces a 10 mm square, and returns to machine zero. Document the complete WebUI LocalFS upload, controller-side content verification, successful $LocalFS/Run execution, Program End response, and final Idle X0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
    [config.yaml]
2026-09-15 Archive gantry mechanical source packages
    Add the requested Gantry_Mechanical downloads under the repository Mechanical tree without modifying or unpacking the source archives. Preserve the bearing STEP models, Ender 3 cable-chain package, a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
    Add a handoff inventory containing archive sizes, SHA-256 checksums verified against the original Downloads copies, summarized contents, licensing notes, duplicate-model context, and a safety warning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
